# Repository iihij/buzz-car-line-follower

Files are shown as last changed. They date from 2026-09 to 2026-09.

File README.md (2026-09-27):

# Buzzi — Line-Following Buzz Car

An educational line-following robot for kids aged 8–10, built by Team Buzzi for **ECE 3011 (ECE Design Fundamentals), Georgia Tech, Spring 2026**.
Buzzi follows a black line with two IR sensors and shows what it is "feeling" through two OLED eyes, a NeoPixel strip and sound, so students can see sensing and feedback control happen in real time. The bill of materials targets about $70 per unit, under a $100 budget.

<p align="center">
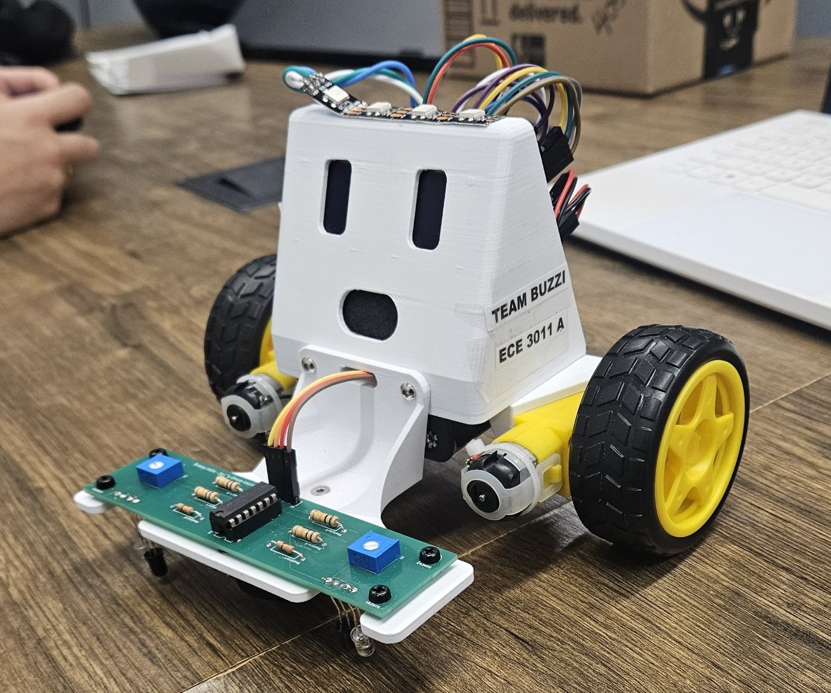
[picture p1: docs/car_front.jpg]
Buzzi, front view
  
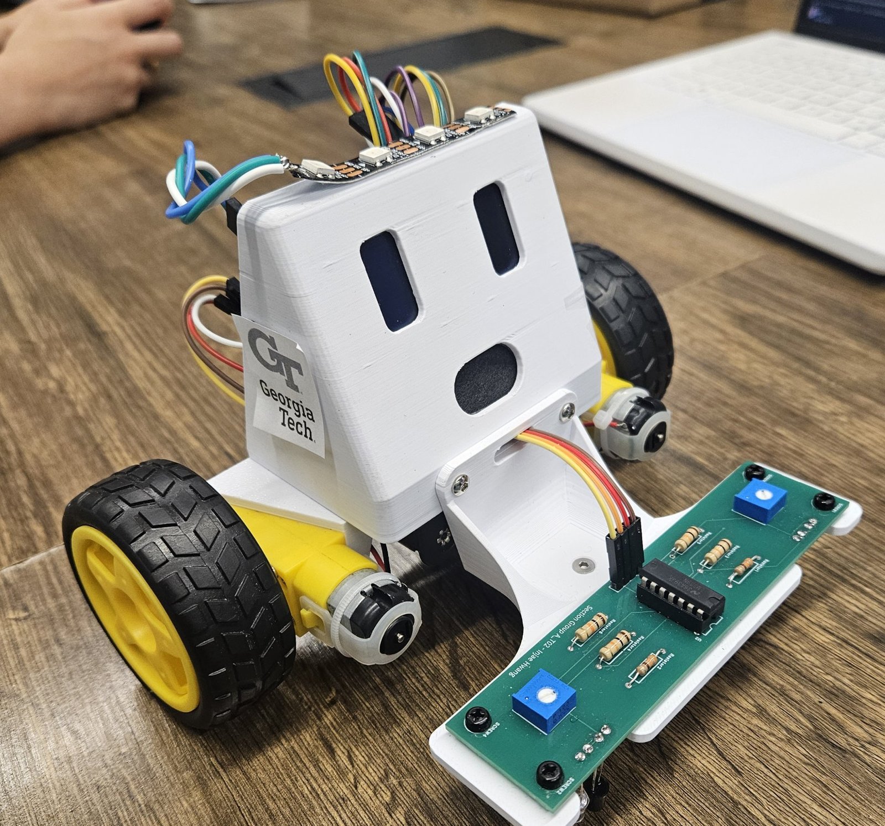
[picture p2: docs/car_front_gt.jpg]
Buzzi, three-quarter view
  
</p>

## System overview

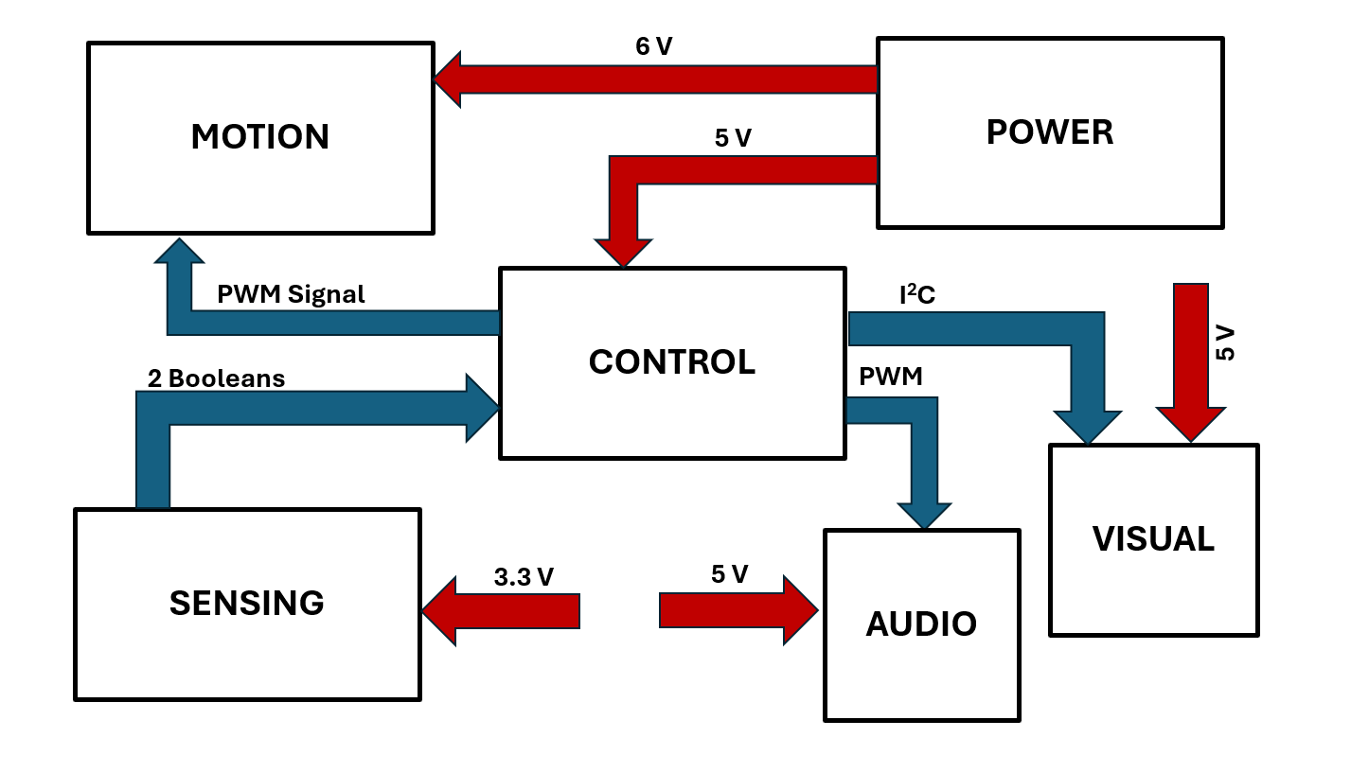
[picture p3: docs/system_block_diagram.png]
System block diagram


| Subsystem | Hardware |
|---|---|
| Control | ESP32-C6-DevKitC-1 |
| Sensing | Two IR LED and phototransistor pairs with an LM339 comparator on a custom sensor board |
| Motion | DRV8833 dual H-bridge, two TT brushed gearmotors, 65 mm wheels |
| Visual | Two 128×64 SSD1306 OLED "eyes" (I²C 0x3C / 0x3D), NeoPixel LED strip |
| Audio | PAM8904 amplifier driving an 8 Ω 1 W speaker from a PWM tone |
| Power | 6 V pack (4 × AA), MPM3610 5 V buck module, 3.3 V rail for the sensor board |

## Measured performance

| Item | Requirement | Measured |
|---|---|---|
| 3.3 V rail | 3.14–3.47 V | 3.31 V |
| 5 V rail | 4.75–5.25 V | 5.08 V |
| Gearmotor output speed at 6 V | ≥ 180 RPM | 210 RPM |
| Speaker loudness | Audible in a classroom | ~82 dB at 1 m |
| Sensor output | Clean digital logic | 0 V over white, 3.3 V over the line |

## Power

The 6 V battery pack drives the DRV8833 motor supply directly. An MPM3610 5 V buck module on the main PCB supplies the ESP32 DevKit, the NeoPixel strip and the audio amplifier. The sensor board is powered from 3.3 V rather than the 5 V pin on the J11 header, so its comparator outputs swing between 0 and 3.3 V and are safe for the ESP32 GPIO.

## Main PCB

<p align="center">
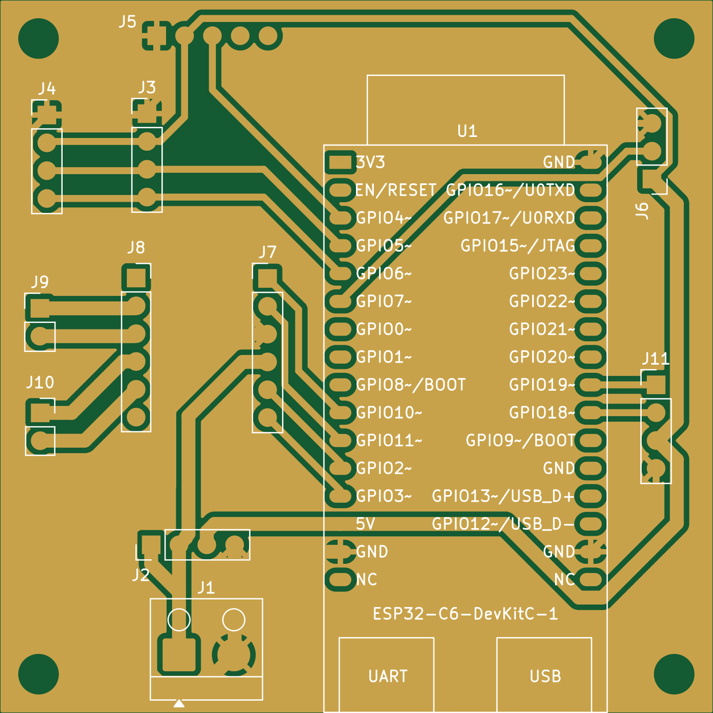
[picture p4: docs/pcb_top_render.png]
Main PCB, top side rendered from Gerbers
  
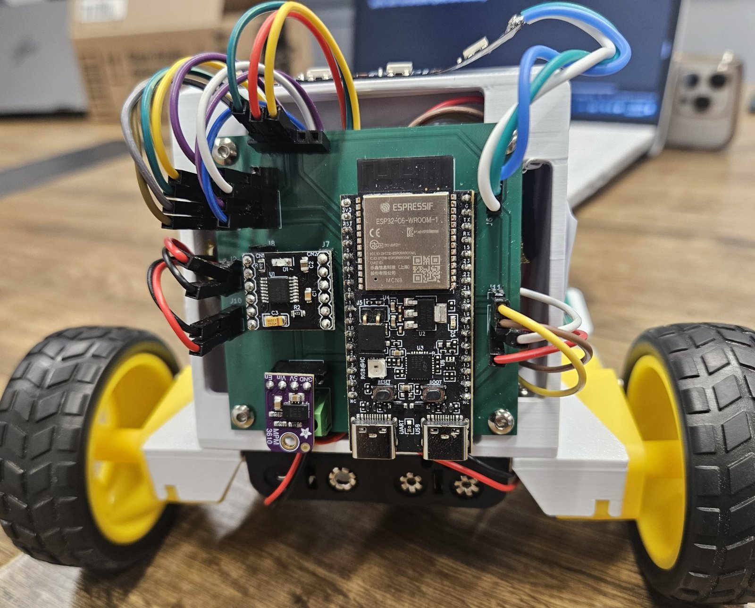
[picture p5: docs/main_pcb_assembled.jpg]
Assembled main PCB on the back of the car
  
</p>

- 2-layer board, 65 × 65 mm, designed in KiCad 9
- Signal routing on the top layer, solid ground pour on the bottom layer
- Plug-in headers for every module, so each subsystem can be swapped or tested on its own
- Four M3 mounting holes; `gerbers.zip` is ready to upload to a PCB fab

| ESP32-C6 pin | Net | Connects to |
|---|---|---|
| GPIO2 / GPIO3 | M1F / M1R | DRV8833, motor 1 |
| GPIO10 / GPIO11 | M2F / M2R | DRV8833, motor 2 |
| GPIO18 | LeftSensor | Sensor header (J11) |
| GPIO19 | RightSensor | Sensor header (J11) |
| GPIO5 | SCL | Left / right OLED (J4, J3) |
| GPIO6 | SDA | Left / right OLED (J4, J3) |
| GPIO7 | LED | NeoPixel (J6) |
| GPIO4 | AMP | Audio amplifier (J5) |

## Sensor board

The sensor board was designed in EasyEDA Pro by Injae Hwang and passed DRC and ERC with zero errors.

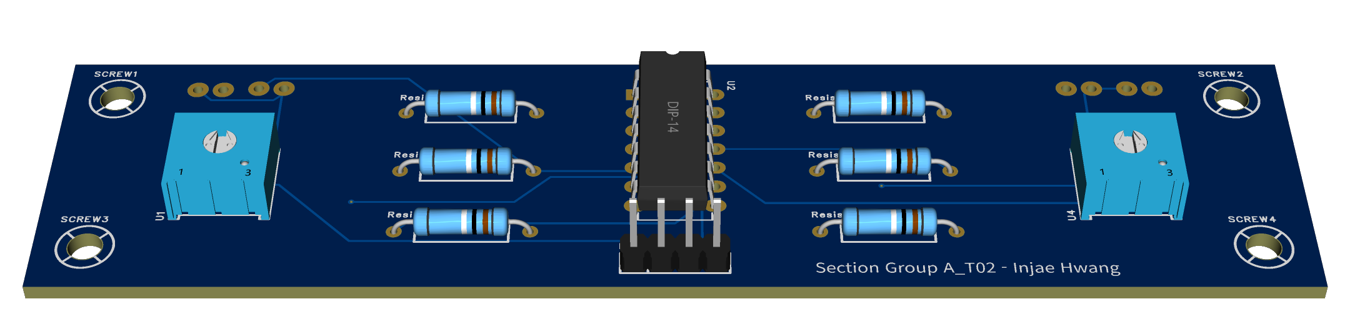
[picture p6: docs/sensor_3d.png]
Sensor board, 3D render


<p align="center">
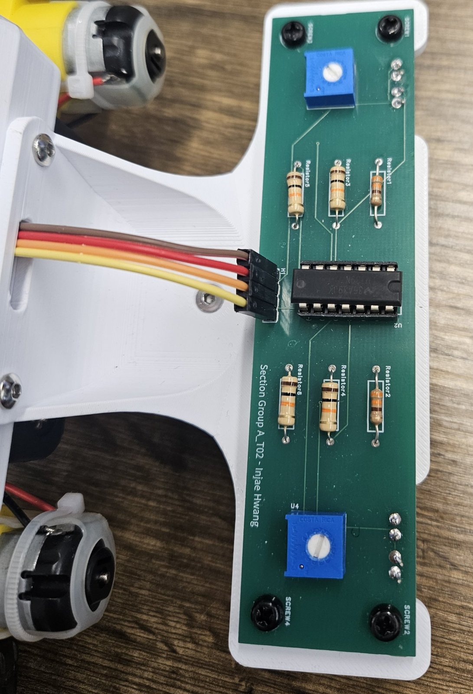
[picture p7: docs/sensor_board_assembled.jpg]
Assembled sensor board mounted on the chassis
  
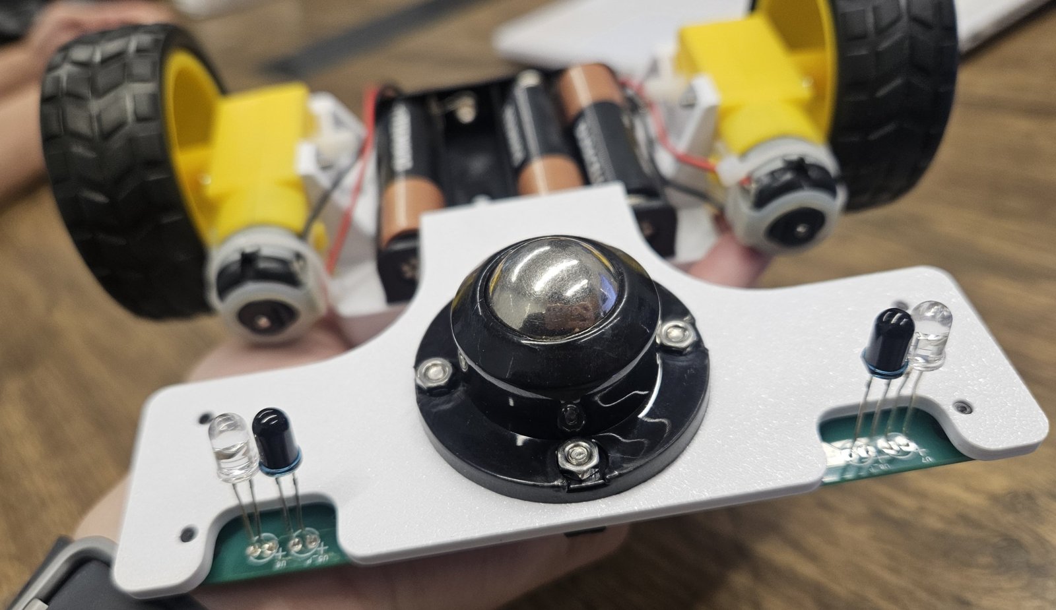
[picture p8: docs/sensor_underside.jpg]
IR LEDs and phototransistors facing the track, with the ball caster
  
</p>

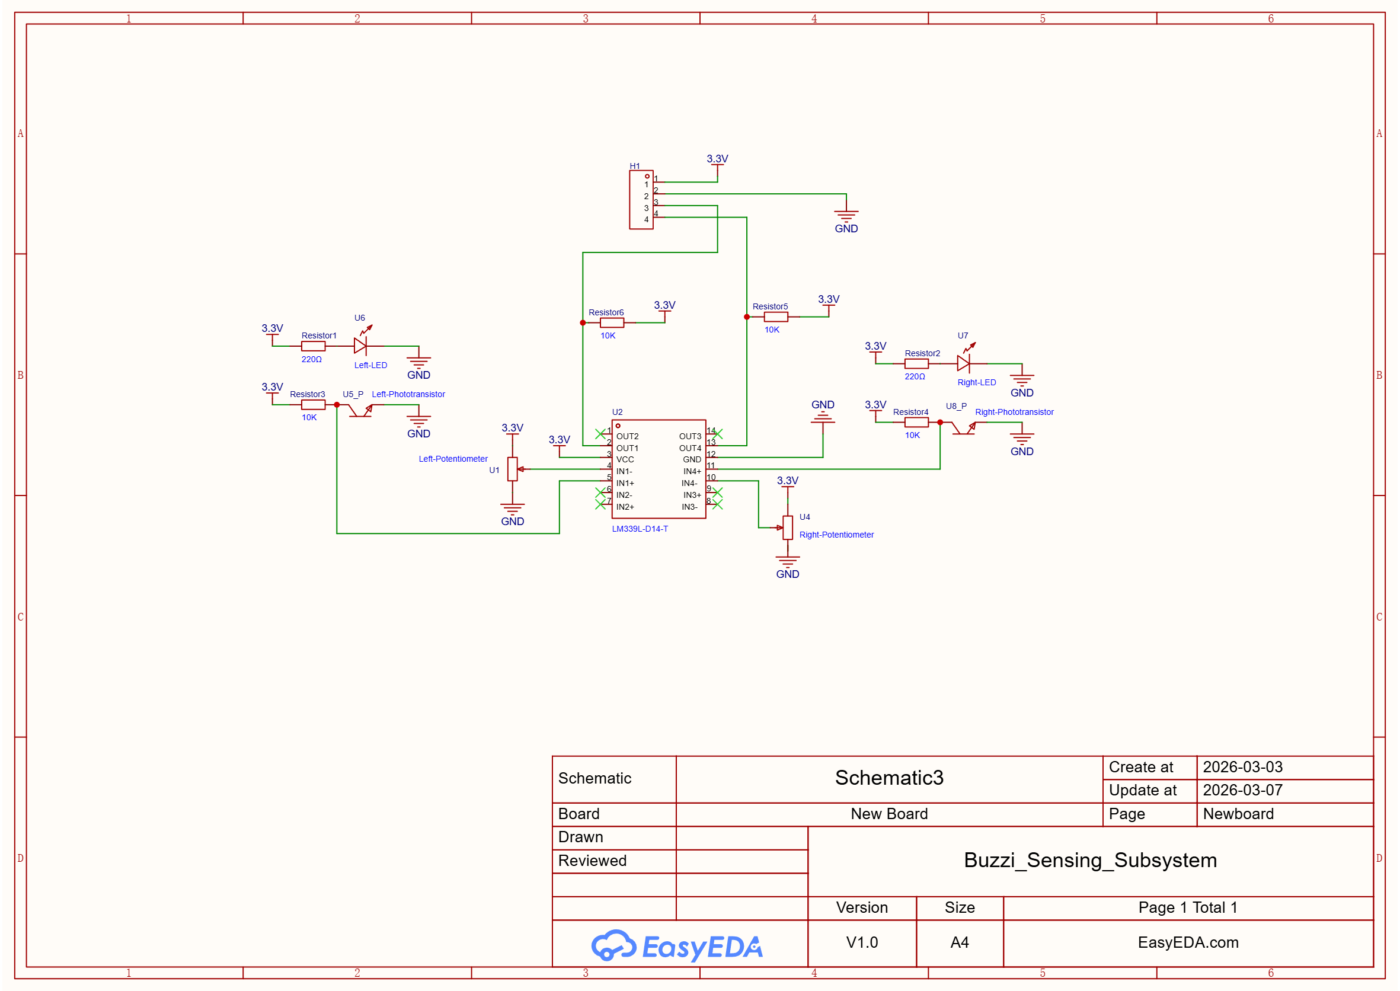
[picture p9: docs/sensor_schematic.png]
Sensor board schematic


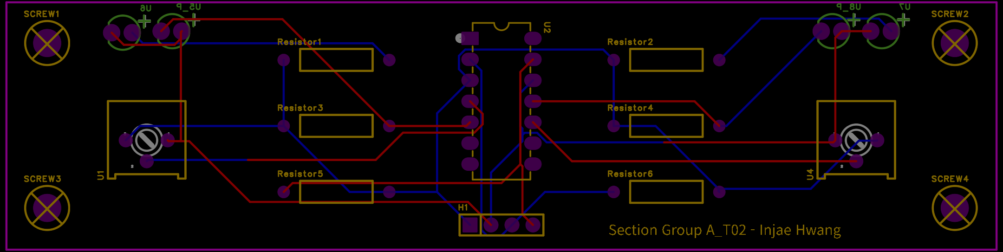
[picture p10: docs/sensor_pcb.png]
Sensor board PCB layout


Each side of the car has an IR LED (220 Ω current limit) and a phototransistor with a 10 kΩ collector resistor, both facing the track. The phototransistor node drives the non-inverting input of one LM339 comparator channel, and a 10 kΩ potentiometer sets the threshold on the inverting input. Over a white surface the phototransistor conducts, the node falls below the threshold and the comparator output goes low. Over the black line the node rises and the output is pulled high by a 10 kΩ pull-up. The ESP32 therefore reads a clean digital HIGH when the sensor is on the line, and each side can be tuned separately for classroom lighting.

The emitters and detectors are mounted through the chassis plate so they face the track, with a ball caster between the two sensor pairs.

A two-sensor digital design was chosen over an eight-sensor analog array: it uses only two GPIO pins and almost no CPU time, which keeps the control loop at 100 Hz or faster.

| H1 pin | Signal |
|---|---|
| 1 | 3.3 V supply |
| 2 | GND |
| 3 | Left output (LM339 OUT1) |
| 4 | Right output (LM339 OUT4) |

Bench bring-up of the sensor prototype found three assembly faults:

1. **Phototransistors inserted with reversed polarity.** After fixing them, the raw analog reading separated clearly: about 160–190 on white and 2800–2900 on black (12-bit ADC counts).
2. **Missing 10 kΩ pull-up resistors on the LM339 outputs.** The LM339 has open-collector outputs, so without pull-ups the digital signal never went high.
3. **Emitter and detector mounted sideways instead of facing the surface.**

All three were assembly errors; the schematic itself was correct. With them fixed, the comparator thresholds were tuned with the potentiometers, and the turn logic was tuned until the car completed the course without leaving the track.

## Mechanical design

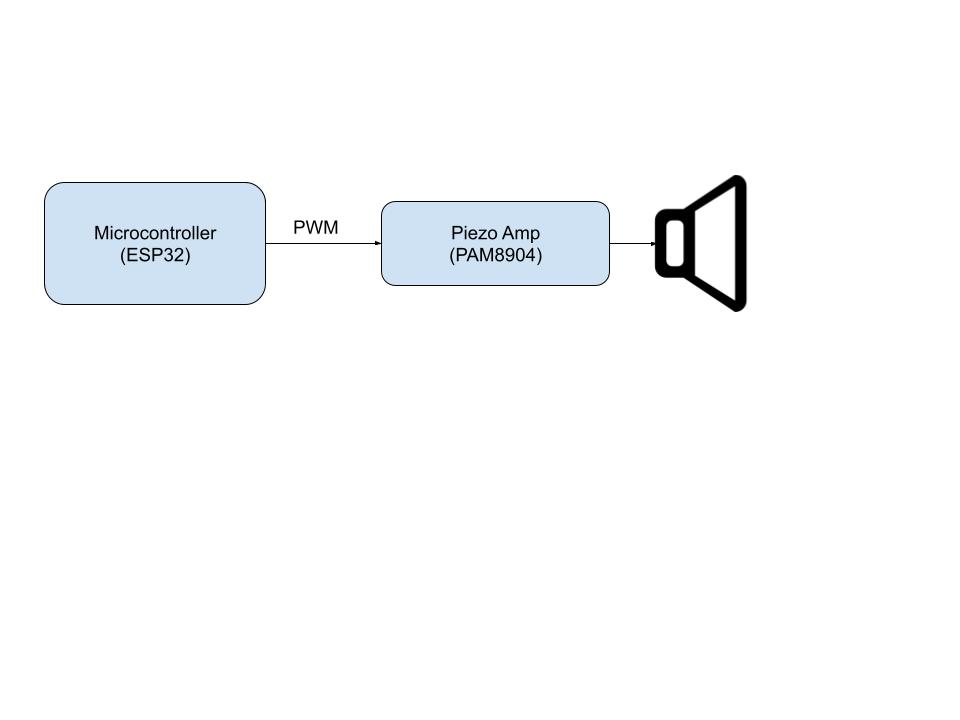
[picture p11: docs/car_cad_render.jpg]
Buzzi mechanical CAD model


The 3D-printed body holds the two OLED eyes and the speaker in the face, the NeoPixel strip along the top edge, the main PCB on the back, and the battery pack between the two TT gearmotors.

## Repository layout

```
project_pcba/   KiCad project for the main PCB (schematic, layout, project file)
gerbers/        Main PCB Gerber and drill files
gerbers.zip     Same files, zipped for fab upload
docs/           Images
```

## Firmware

<!-- TODO: add the Arduino sketch to firmware/ and delete this comment -->

Built with the Arduino IDE for the ESP32-C6. Library dependencies: Adafruit GFX, Adafruit SSD1306, Adafruit NeoPixel.

## Team

Team Buzzi, ECE 3011 Section A_T02, Spring 2026. Instructor: Dr. Timothy Brothers.

| Member | Role |
|---|---|
| Injae Hwang | Sensing subsystem lead: sensor board design, LM339 comparator analysis, sensor test plan |
| Kevin Niu | Motion subsystem lead: mechanical design and TT motor integration |
| Jolson Zheng | Audio and visual subsystem lead: OLED eyes, NeoPixels and speaker |
| Tejaswi Manoj | Power and control subsystem lead: power distribution and ESP32 control logic |

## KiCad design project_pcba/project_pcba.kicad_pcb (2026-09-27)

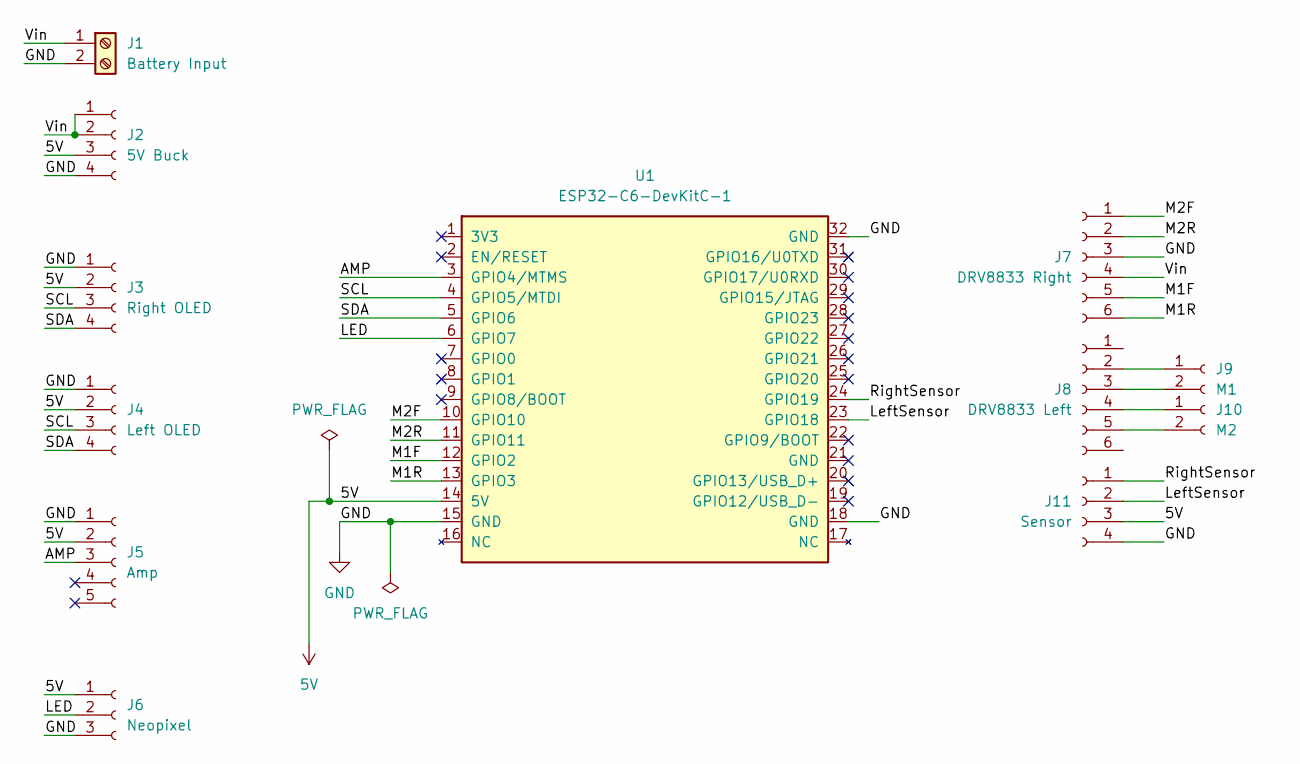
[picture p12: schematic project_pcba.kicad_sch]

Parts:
J1: Battery Input; Altech_AK100_1x02_P5.00mm
J2: 5V Buck; PinHeader_1x04_P2.54mm_Vertical
J3: Right OLED; PinHeader_1x04_P2.54mm_Vertical
J4: Left OLED; PinHeader_1x04_P2.54mm_Vertical
J5: Amp; PinHeader_1x05_P2.54mm_Vertical
J6: Neopixel; PinHeader_1x03_P2.54mm_Vertical
J7: DRV8833 Right; PinHeader_1x06_P2.54mm_Vertical
J8: DRV8833 Left; PinSocket_1x06_P2.54mm_Vertical
J9: M1; PinHeader_1x02_P2.54mm_Vertical
J10: M2; PinSocket_1x02_P2.54mm_Vertical
J11: Sensor; PinHeader_1x04_P2.54mm_Vertical
U1: ESP32-C6-DevKitC-1

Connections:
5V: J2.3, J3.2, J4.2, J5.2, J6.1, J11.3, U1.14 (5V)
/AMP: J5.3, U1.3 (GPIO4/MTMS)
/LED: J6.2, U1.6 (GPIO7)
/LeftSensor: J11.2, U1.23 (GPIO18)
/M1F: J7.5, U1.12 (GPIO2)
/M1R: J7.6, U1.13 (GPIO3)
/M2F: J7.1, U1.10 (GPIO10)
/M2R: J7.2, U1.11 (GPIO11)
/RightSensor: J11.1, U1.24 (GPIO19)
/SCL: J3.3, J4.3, U1.4 (GPIO5/MTDI)
/SDA: J3.4, J4.4, U1.5 (GPIO6)
/Vin: J1.1, J2.1, J2.2, J7.4
GND: J1.2, J2.4, J3.1, J4.1, J5.1, J6.3, J7.3, J11.4, U1.15 (GND), U1.18 (GND), U1.32 (GND)
unnamed: J8.2, J9.1
unnamed: J8.3, J9.2
unnamed: J8.4, J10.1
unnamed: J8.5, J10.2

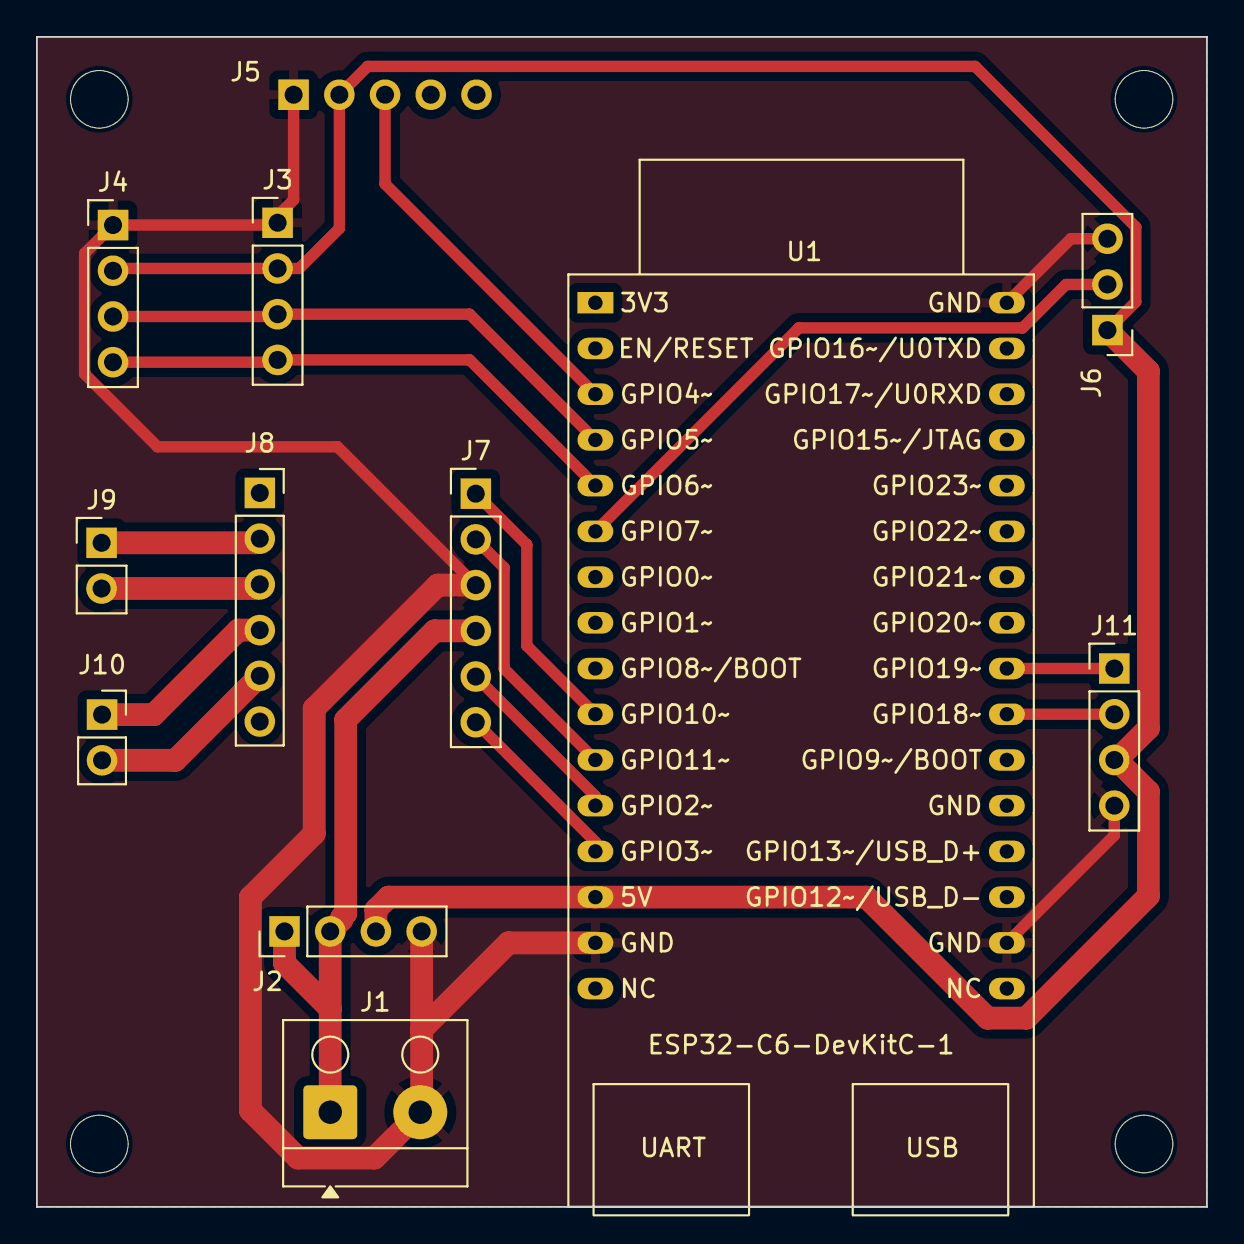
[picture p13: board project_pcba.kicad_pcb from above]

Board: 2 copper layers, 65.0 x 65.0 mm, 12 parts (1 on the bottom side), 17 nets.
